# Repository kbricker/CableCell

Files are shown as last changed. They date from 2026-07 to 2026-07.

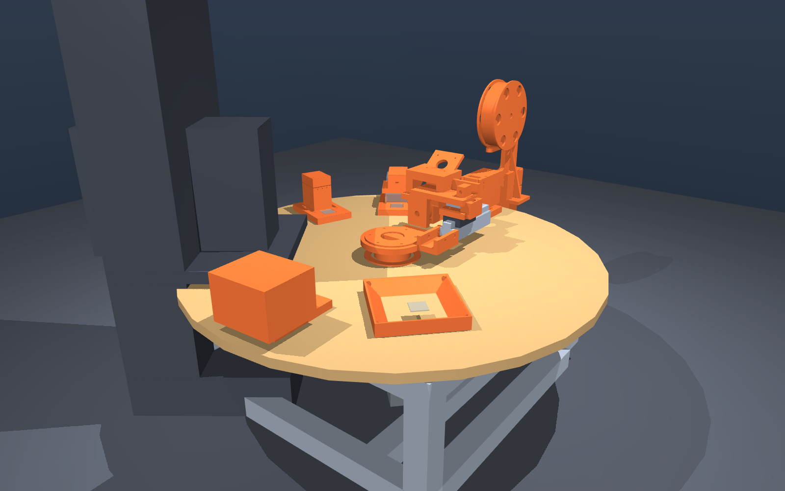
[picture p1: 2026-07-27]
sim/studies/renders/make_overview.png

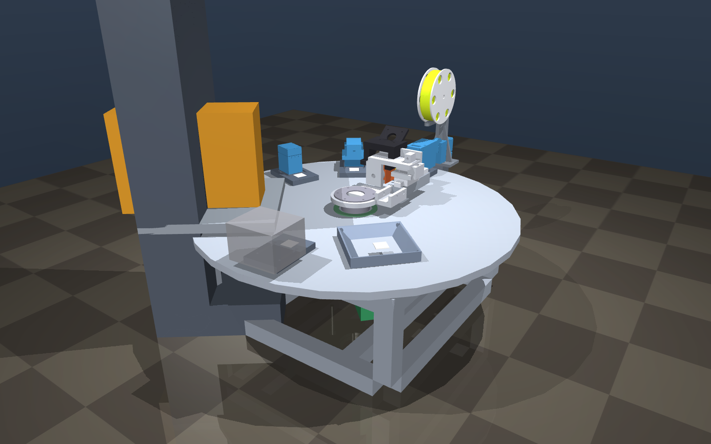
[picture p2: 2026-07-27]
sim/studies/renders/roughin_overview.png

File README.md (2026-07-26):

# CableCell

A benchtop robot cell that takes 22 AWG 3-conductor servo ribbon off a spool and
produces finished cables — split, strip, crimp Molex 5263 chain terminals, insert
into Mini-SPOX 5264 housings (50-37-5033, TRUE 2.50 mm pitch) on both ends, at a
commanded length.

> Load 20 housings into the cassette, a spool of ribbon, and a reel of pins.
> Tell the software: **3 cables, 5 inch total length.** It makes them and they
> drop into the collect bin as they complete.

**Architecture:** rotary indexing dial — six fixed stations on a bolt circle,
one arm carries the work to each. See `docs/cell-design.md`.

**First customer:** TendWright's STS3215 servo bus needs ~6–10 exact-length
joint-to-joint runs. That is a customer relationship, not ownership — CableCell
is its own project.

## Status

**Planning / design / simulation.** No code, no hardware, nothing ordered. The
sequence is deliberate: plan → research → design → simulate → source → build.
We do not buy until the sim says the layout closes.

## Layout

| Folder | Contents |
|---|---|
| `docs/` | Design of record, prior-art survey, decision log, sourcing index |
| `components/` | `registry.yaml` — the join between the BOM and the sim |
| `bom/` | Rendered buy lists with live vendor links |
| `cad/` | Vendor STEP files as downloaded, before conversion |
| `sim/` | MuJoCo rough-in: datums, scene assembly, reach/collision studies |
| `hardware/` | Printed and machined parts, once they exist |

## The component registry

`components/registry.yaml` is the single source of truth that both the BOM and
the simulation read. One entry per physical component: spec, vendor link, price,
sourcing status, and its model (CSG primitive parameters, or a mesh path once we
have a real one). Two lists that describe the same machine will drift; one list
that renders two views cannot.

## Modeling split

- **MuJoCo + CSG primitives** — layout and motion truth. Does the arm reach every
  station, does anything collide, does the cycle close. Precision does not live
  here; MuJoCo tessellates everything anyway.
- **FreeCAD (B-rep)** — manufacturing truth. Reads vendor STEP without fidelity
  loss, exports STL for the sim at a controlled deviation, and produces the
  dimensioned fabrication drawings via TechDraw.
- **Blender** — renders, visual mockups, quick blockouts.

## Hive

- **App:** CableCell (id 9) · modules Design / Applicator / Stations / Motion / Sourcing
- **Plan:** #657 — sourcing, de-risk bench, DIY ribbon-fed applicator

## License

This repository is dual-licensed, because it contains two different kinds of
work and a software license does not cleanly cover a CAD file.

| What | License | File |
|---|---|---|
| Software — `sim/`, scripts, anything executable | **MIT** | [`LICENSE`](LICENSE) |
| Documentation, CAD, hardware designs, BOMs — `docs/`, `cad/`, `hardware/`, `components/`, `bom/` | **CC BY 4.0** | [`LICENSE-CC-BY-4.0.txt`](LICENSE-CC-BY-4.0.txt) |

In plain terms: **take the code and do what you like as long as you keep the
copyright notice; take the designs and do what you like as long as you credit
me.** CC BY requires visible attribution in a way MIT does not — MIT only asks
that the license text travels with copies, which is notice preservation rather
than credit.

Neither license grants patent rights explicitly. That is deliberate.

Copyright (c) 2026 Kyle Bricker.

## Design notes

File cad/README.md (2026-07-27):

# cad/

Printed and machined parts as real CAD solids.

```
"%LOCALAPPDATA%/Programs/FreeCAD 1.1/bin/freecadcmd.exe" cad/build_parts.py
```

Regenerates everything in `parts/`. Each part exports three ways:

| Extension | For |
|---|---|
| `.FCStd` | open and edit in FreeCAD |
| `.step` | B-rep — other CAD, and TechDraw drawings |
| `.stl` | slicer, and mesh swap-in for the MuJoCo scene |

**Dimensions come from `sim/layout.py`**, the same single source the simulation
uses, so the printable parts and the sim cannot drift. Change a number there and
re-run both.

---

## Current parts

| Part | Size (mm) | Volume | What it is |
|---|---|---|---|
| `spool` | 110 × 110 × 31 | 116.6 cm³ | S1 ribbon spool. The wire ships as a loose roll, so this is ours to define |
| `spool_hanger` | 70 × 44 × 150 | 81.0 cm³ | Carries the spool axle, mounts to 3030 on 30 mm centres |
| `dancer_arm` | 82 × 12 × 20 | 6.2 cm³ | Passive tension; its flag is the spool-empty detect |
| `comb` | 26 × 32 × 12 | 9.3 cm³ | The gripper — a 3-channel **guide**, not a clamp |
| `guide_tube_mount` | 34 × 24 × 29 | 14.4 cm³ | Holds the PTFE tube that sets S1's presentation point |
| `measuring_wheel` | 31.8 × 31.8 × 9 | 5.3 cm³ | **Owns cable length accuracy.** 31.83 mm dia = 100.00 mm circumference |
| `spreader_plate` | 25 × 32 × 8 | 6.0 cm³ | S2's fan — diverging slots, 1.45 → 8 mm pitch over 25 mm |
| `z_platform` | 208 × 208 × 24 | 295.1 cm³ | Rides three posts, driven by one **off-axis** screw. Resolves the coaxial conflict |
| `radial_carriage` | 52 × 45 × 22 | 21.2 cm³ | MGN12 carriage + T8 nut. Takes the ~50 N pull-off thrust |
| `wrist_mount` | 50 × 32 × 26 | 12.0 cm³ | Carries the comb, flips 180° on mechanical hard stops |
| `camera_mount` | 60 × 48 × 34 | 29.5 cm³ | ELP board on the radial carriage — **not** the wrist, which flips |
| `drive_roller_block` | 56 × 30 × 46 | 67.0 cm³ | S1 feed nip. Drives and retracts; deliberately does **not** measure |
| `guillotine_holder` | 44 × 34 × 54 | 75.1 cm³ | S1 cut. Replaceable blade, close anvil clearance to shear not crush |
| `station_mount` | 76 × 60 × 40 | 46.6 cm³ | Generic station base with radial slots and an AprilTag ledge |

---

## Print notes

**Material.** *PETG where sustained load, creep or impact dominates; PLA+ where
dimensional accuracy or fine features dominate.* PLA creeps under constant
room-temperature stress in a way PETG does not, so anything permanently loaded is
PETG — `z_platform`, `station_mount`, `spindle_shaft`, `spool_hanger`,
`guillotine_holder`, `drive_roller_block`, `radial_carriage`, `wrist_mount`.

Everything else is PLA+, including — **revised** — the **comb**. An earlier note
here put the comb in PETG for toughness. That was the wrong call: its 1.8 mm
channels are the functional fit, sharper features beat toughness, and the load is
guide-only. Same reasoning puts `measuring_wheel` and `spreader_plate` in PLA+.

Per-part table and quantities in [`bom/bom-phase1.md`](../bom/bom-phase1.md) §7.
One 1 kg spool of each covers the build: ~720 g PETG, ~139 g PLA+.

**The comb is the part to be careful with.** Its channels are nominally
1.8 mm for a 1.4 mm conductor: only 0.2 mm clearance per side, and **FDM will
eat most of that.** Expect a 1.8 mm modelled slot to come out nearer 1.6 mm.
Print a short test coupon and check a conductor slides freely before committing
to a full comb — the channels must *guide*, never grip, or the whole
one-conductor-at-a-time premise fails.

**Orientation:**

| Part | Orientation | Why |
|---|---|---|
| `spool` | flange flat on the bed | Bore prints as a true vertical circle; no supports except the ribbon anchor slot |
| `spool_hanger` | on its back, upright flat on the bed | Axle bore axis vertical = round. Gussets and base need light support |
| `dancer_arm` | flat, as modelled | Trivial, no supports |
| `comb` | channels facing up | Channels are open-topped so they self-support; the lead-in funnels are the only overhang |
| `guide_tube_mount` | on its side, tube bore vertical | A horizontal 4 mm bore will sag; vertical prints round |
| `measuring_wheel` | flat, bore vertical | Rim concentricity is everything here — a wobbling wheel measures wrong |
| `spreader_plate` | flat, slots vertical through the plate | The lofted slots self-support; flared entries are the only overhang |
| `drive_roller_block` | on its back, motor face down | Keeps the ribbon slot and idler slot on the same layer plane, so the nip stays square |
| `guillotine_holder` | upright as modelled | **The 0.9 mm blade guideway is the critical feature** — print it vertical or it will not be straight |
| `station_mount` | flat, tag ledge up | Slots print clean; the ledge overhang is shallow enough to bridge |

**The measuring wheel has no rubber, deliberately.** A tyre or O-ring would grip
better but changes the effective circumference, and its compression varies with
preload — which is precisely the error the wheel exists to avoid. Grip comes from
a printed axial knurl plus light spring preload. Even so, treat 100.00 mm as
*nominal*: effective circumference depends on how far the ribbon compresses, so
it is a calibration constant measured at commissioning, not a number to trust.

**Tolerance reality.** Everything with a bore is modelled at nominal +0.15 mm
(the 8 mm axle bores are 8.3 mm) because printed holes come out undersize. The
comb channels are *not* similarly padded — they are a functional fit and want
measuring, not guessing.

---

## Two FreeCAD scripting traps, recorded so nobody re-finds them

1. **`Shape.translate()` mutates in place and returns `None`.** Chaining it —
   `face.extrude(v).translate(v2)` — silently yields `None`, and fusing that
   kills `freecadcmd` outright with no traceback. Build geometry at its final
   position instead, or use `translated()`.
2. **`freecadcmd` sets `__name__` to the module basename, not `"__main__"`.**
   A conventional `if __name__ == "__main__":` guard never fires, so the script
   imports cleanly and does absolutely nothing. `build_parts.py` accepts both.

Also worth knowing: routing an STL through a `Mesh::Feature` document object and
`Mesh.export()` crashes the process. Write the mesh directly —
`Mesh.Mesh(shape.tessellate(dev)).write(path)`.

`freecadcmd` swallows stdout and can die without a traceback, so
`build_parts.py` writes `cad/build.log` step by step. If a run produces nothing,
read that first.

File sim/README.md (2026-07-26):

# sim/

MuJoCo CSG rough-in. Answers **reach, collision and cycle-closure** — not
precision. MuJoCo tessellates everything; manufacturing truth lives in FreeCAD.

| File | What it does |
|---|---|
| `layout.py` | **The single source of every dimension.** Nothing else may hard-code one. Millimetres and degrees; each value carries a provenance status (COMMITTED / ESTIMATED / PLACEHOLDER) |
| `build_scene.py` | Generates `assets/cell.generated.xml` from `layout.py`; `--render` also writes PNG views |
| `run_cell.py` | Interactive viewer — regenerates the scene first, so edit-a-dimension-and-rerun is the whole loop |
| `studies/fit_check.py` | Arithmetic-only layout check: angular fit, Z budget, press reach |
| `studies/renders/` | Rendered views, committed so the layout can be reviewed without running anything |

## Run

```
uv sync
uv run python -m sim.layout                  # provenance: what is real, what is not
uv run python -m sim.studies.fit_check       # does the layout close?
uv run python -m sim.build_scene --render    # write MJCF + PNGs
uv run python -m sim.run_cell                # interactive viewer
```

## Frame convention

- world `z = 0` is the **bench top**
- world `x = y = 0` is the **pivot axis** (Datum B)
- the deck (Datum A) sits at `layout.DECK_ABOVE_BENCH`
- conversion mm → m happens once, in `build_scene.py`, never in `layout.py`

## Axes

Five joints model the arm: `Z` (assembly lift), `T` (theta, rotate), `R` (extend),
`S` (comb cross-slide), `W` (wrist flip). Ribbon feed (`F`) and nest index (`H`)
are station-local and not part of the arm kinematics.

`assets/cell.generated.xml` is generated — do not edit it. Change `layout.py`.

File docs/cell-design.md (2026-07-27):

# CableCell v1 — Full Design Document

**Date:** 2026-07-24 · **Hive:** app 9 (CableCell), plan #657
**Supersedes:** the layout sketches in `exploration-and-thumbnail.md` (that doc remains the prior-art survey and decision log).
**Architecture:** rotary dial (Kyle 2026-07-24) — fixed stations on a bolt circle, one arm carries the work to them.

---

## 1. The job this machine exists to do

> Load 20 housings into the cassette, a spool of ribbon, and a reel of pins. Tell the software: **3 cables, 5 inch total length.** It makes them and they drop into the collect bin as they complete.

That is the acceptance test, stated as a spec:

| | |
|---|---|
| **Input consumables** | 20× Molex 50-37-5033 housings (cassette) · 1 spool 22 AWG 3-conductor servo ribbon · 1 reel Molex 0008701039 terminal chain |
| **Job command** | `qty=3, length=127.0 mm (5.00"), recipe=SPOX-3P` |
| **Output** | 3 finished cables, connector on both ends, in the collect bin |
| **Consumed** | 6 housings, 18 terminals, ~420 mm of ribbon (3 × 127 mm + kerf/lead-in) |
| **Untouched** | 14 housings still in the cassette |
| **Unattended** | Yes — operator loads, presses Run, walks away |

**Length definition (matters, gets calibrated):** *total length* = tip of connector A to tip of connector B. The machine works internally in **ribbon length** and applies a per-recipe constant (`connector_offset`) for the amount of wire consumed inside each housing. Calibrate once by measuring a produced cable; store in the recipe.

**Length envelope:** minimum ~90 mm (set by 2 × split length + handling clearance), maximum ~1000 mm (set by the payout trough). 127 mm sits comfortably in range.

**Capacity per load:** 20 housings = 10 cables. A 15 m ribbon spool at 127 mm = ~110 cables. A 5000-terminal reel = ~830 cables. **Housings are the binding constraint** — by design, since they're the one thing a human loads by hand.

---

## 2. Machine overview

A rotary indexing cell. Six stations sit on a bolt circle. One **arm** pivots between them and extends radially into whichever station it faces. Nothing else moves the workpiece.

```
                       ┌──────── S2 SLIT + FAN ────────┐
                       │                                │
        S1 FEED / CUT ─┤          ●  pivot              ├─ S3 STRIP
        (spool, rollers│         ╱                      │
         guillotine)   │        ╱  arm  ──► extends     │
                       │       ╱   radially into        │
        S6 DROP ───────┤          whichever station     ├─ S4 CRIMP
        (collect bin + │          it is facing          │   (press +
         reject bin)   │                                │    applicator)
                       └──────── S5 INSERT ─────────────┘
                                 (housing cassette,
                                  nest, pusher)
```

**Why rotary:** repeatability comes from mechanical detents at each sector rather than a long rail staying square; each station is a bolt-on module in its own sector (which is precisely how "other connectors later" arrives — a new insert sector plus a new cassette); and the circle fits the working stations in less bench space than a 900 mm rail. The reject bin costs nothing — it is simply another angular position.

> **Bolt circle corrected 2026-07-26.** This section previously claimed a ~300 mm circle. It does not close: seven stops (six stations plus reject) with a 210 mm-wide press need **274.4° of a 270° arc** at R₀ = 150 mm. The working value is **R₀ = 200 mm** — a 400 mm circle — which needs 201.8° and leaves 68° spare. Minimum viable is ~175 mm. Computed by `sim/studies/fit_check.py`; table in `docs/datums.md`. The original figure was written for *five* stations, before the press was understood as a standalone machine.

**Working arc, not a full turn.** The arm sweeps ~270° and returns. The trailing ribbon sweeps with it but never wraps the pivot, so no slip ring and no rotary air union are needed — a service loop and drag chain carry power and air to the arm.

### 2.1 The arm (the only thing that moves the work)

Three things ride on the arm:

- **Comb** — the gripper. Not a plain clamp: a **3-channel guide** that keeps each conductor individually addressable. The channels *guide*; they do not clamp. The **ribbon body is clamped** behind the split, so each conductor can slide freely in its own channel — which is what lets a pusher advance one conductor at a time at the insert station.
- **Cross-slide** — a short lateral axis (~20 mm) that indexes which conductor sits on the station work line. One conductor at a time to the crimp anvil; one conductor at a time to the insertion axis. Comb channel pitch is **8 mm**, deliberately *not* the 2.5 mm connector pitch — see §5.4.
- **Wrist** — a 180° flip. Needed because the two ends of a cable are born pointing in opposite directions (§3, step 7). It only ever needs two positions, so it is a **pneumatic rotary actuator with adjustable hard stops**, not a servo.

---

## 3. Full cycle — one cable, step by step

Running the 3 × 127 mm job. Steps 1–13 repeat three times.

**End A (still attached to the spool — the spool is the anchor)**

1. **Present.** Feed rollers advance ribbon until ~30 mm protrudes past the guillotine at S1.
2. **Grip.** Arm at S1, comb closes on the ribbon body; ~28 mm of tail projects radially outward.
3. **Slit + fan (S2).** A two-blade die notches both webs back 25 mm from the tip. A spreader plate then splays the three tails into the comb's 8 mm channels. Ribbon body stays clamped throughout.
4. **Strip (S3).** A 3-position V-blade die closes on all three conductors at comb pitch; the arm retracts ~4 mm to slip the slugs. Strip length 2.5–3 mm. Three slugs drop to the waste chute.
5. **Crimp ×3 (S4).** For each conductor *i*: cross-slide indexes conductor *i* onto the anvil line → station wire-clamp holds it → press fires one stroke → applicator crimps the terminal and severs it from the carrier → load cell records the force curve → cross-slide advances 8 mm. Carrier scrap exits to its own bin. Three pins now stand on the fanned tails at 8 mm spacing.
6. **Insert ×3 (S5).** Escapement drops one housing from the cassette into the nest; nest clamp closes. Then for each conductor *i*: cross-slide brings conductor *i* onto the **fixed insertion axis** → pusher finger closes on the wire ~5 mm behind the pin → drives forward until the housing lance clicks → pulls back 1.5 mm against a stop (retention test, load cell) → releases → **nest indexes one 2.5 mm pitch** so the next cavity arrives on the same fixed axis. Already-inserted conductors travel *with the housing*, so nothing is strained and the tooling only ever works at one spot. Camera checks black/red/white land in cavities 1/2/3. Nest clamp opens; end A is complete.

**Payout and cut**

7. **Pay out.** Arm returns to a defined **payout reference position** holding the finished end A, so the tube-to-comb distance is a known constant. Feed rollers pay out ribbon until `ribbon_length = 127 mm − connector_offset`, measured by the independent encoder wheel (not by counting steps — ribbon slips). Slack sags into the payout trough.
8. **Hand off.** Arm releases end A into the trough and returns to S1, gripping the ribbon on the *piece* side of the guillotine.
9. **Cut.** Guillotine severs. The arm now holds the cable by end B; the finished connector A dangles in the trough. The spool's new leading end waits at the tube for the next cable.
10. **Flip.** Wrist rotates 180°, so end B's tail now projects radially outward exactly as end A's did in step 2. **Every station sees identical geometry for both ends** — this is what the wrist buys, and why it isn't optional.

**End B**

11. **Repeat 3–6** on end B. Same stations, same tooling, same motions, second housing.
12. **Drop.** Arm indexes to S6 over the collect bin, comb and body clamp open, finished cable falls. On any fault flag (crimp force out of band, retention fail, camera mismatch) the arm drops at the **reject** angle instead and logs why.
13. **Next.** Feed rollers advance the spool's new leading end past the guillotine. Go to step 2.

**Job end:** after cable 3, the machine parks, reports `3/3 complete, 0 rejects, 6 housings used, 14 remaining`, and idles.

---

## 4. Cycle time

| Phase | Ops | Est. |
|---|---|---|
| Grip + slit + fan + strip | 4 moves, 3 strokes | ~12 s |
| Crimp ×3 | 3 index + 3 strokes | ~15 s |
| Insert ×3 | 3 index + 3 push/verify + 3 nest index | ~20 s |
| **Per end** | | **~47 s** |
| Payout, handoff, cut, flip | | ~15 s |
| **Per cable** (2 ends + payout) | | **~110 s** |
| **3 × 127 mm job** | | **~5.5 min** |

Commercial machines do this in 7–9 s per cable. We are ~15× slower and roughly 40× cheaper — the right trade for batches of ten.

---

## 5. Mechanical parts — what each one is for

### 5.1 Frame and rotary axis

| Part | Function |
|---|---|
| Aluminum extrusion frame (3030) + 10 mm tooling-plate deck | Rigid datum (Datum A). Every station bolts to the deck on the same bolt circle, so station geometry is set by hole position, not by shimming. |
| **Z stage** — commodity ballscrew linear module (SFU1605 + dual rails + NEMA 17/23) | **Carries the entire rotating assembly.** Lets each station have its own engagement height instead of forcing all seven to one shimmed plane, and provides vertical clearance for rotation. Stack is base → Z → rotary → arm. Stiffness-critical: it sits at the bottom of a long lever, so its compliance shows up magnified at the comb. Prefer the shortest travel that works. See `datums.md`. |
| **Main bearing** — large-bore thin-section or tapered roller, ~80–100 mm | Carries the arm. Must take the *radial extension load* and the reaction from insertion pushes without deflecting more than ~0.05 mm at the comb. |
| Arm rotary drive — NEMA 17 + 5:1 belt reduction, or NEMA 23 direct | Indexes between sectors. Reduction buys resolution and holding torque against station reaction forces. |
| **Detent/index plate** — hardened bushing + spring-loaded or pneumatic plunger per sector | Repeatability. The stepper gets *near* the sector; the detent puts it *exactly* there. This is why rotary beats linear on precision-per-dollar. |
| Drag chain / service loop | Carries the arm's air lines (comb clamp, wrist), stepper cable, and sensor wiring across a ±135° sweep **plus the Z stroke**. No slip ring needed. |

### 5.2 The arm assembly

| Part | Function |
|---|---|
| Radial slide — MGN12 rail + carriage, belt or leadscrew, NEMA 17 | The shared "extend into the station" motion. Every station uses it; this is the big saving of the rotary layout. |
| **Comb** — machined or printed 3-channel guide, hardened channel inserts | Keeps each conductor individually addressable and at a known pitch. Channels guide only. Swappable per connector recipe. |
| **Body clamp** — pneumatic cylinder + serrated pad | Clamps the *unsplit ribbon* behind the comb. This is the actual grip; it takes all handling load, so conductors stay free to slide. |
| Cross-slide — MGN9 + 20 mm leadscrew, NEMA 17 | Indexes conductor *i* onto the work line at crimp and insert. |
| **Wrist** — pneumatic 180° rotary actuator with adjustable stops | Flips end B into end A's orientation. Two positions only, so no servo. |

### 5.3 S1 — Feed / measure / cut

| Part | Function |
|---|---|
| Spool holder + spring dancer arm | Passive payoff at constant light tension; dancer flag doubles as spool-empty detect. |
| Drive rollers (knurled steel + polyurethane idler, spring preload) NEMA 17 | Pays ribbon out and pulls it back. |
| **Measuring wheel + rotary encoder** (independent of the drive) | Owns cable length accuracy. Never trust drive-roller steps — ribbon slips. Closed loop on this encoder. |
| PTFE-lined guide tube | Delivers the ribbon to a repeatable presentation point regardless of spool behaviour. |
| **Guillotine** — hardened blade + anvil, pneumatic | Square full-width cut. Blade geometry must not crush the ribbon end (a crushed end won't enter the comb channels). |
| Payout trough | Receives slack and the dangling finished end A during payout. Keeps a 1 m cable out of the mechanism. |

### 5.4 S2 — Slit + fan

| Part | Function |
|---|---|
| **Two-blade slitting die**, depth-adjustable to 0.05 mm, pneumatic | Notches both webs simultaneously to the recipe's split length (25 mm). Depth control is the whole game — too shallow and it won't zip, too deep and it nicks copper. |
| Spreader plate — diverging slots, pneumatic | Splays the three split tails from the ribbon's **1.40 mm** pitch out to comb pitch (8 mm) and captures them in the comb channels. **7.5° splay** — gentle enough to take no set in the insulation. |
| Backing anvil | Supports the ribbon so the blades cut rather than push. |

**Ribbon pitch is 1.40 mm, not 2.5 mm** (vendor spec 2026-07-27; the 2.5 mm was the connector cavity pitch borrowed by mistake). And the ribbon is **designed to separate by hand**, which may reduce this station to a printed splitting wedge — see `docs/stations.md` §2.

**Why 8 mm and not 2.5 mm:** the fan pitch is a free parameter, and widening it is what removes the pin-to-pin collision risk at the crimp anvil. Convergence back to the connector's 2.5 mm never happens mechanically — pins are inserted one at a time, so the cross-slide handles it in software.

### 5.5 S3 — Strip

| Part | Function |
|---|---|
| 3-position V-blade die at comb pitch, pneumatic | Scores all three conductors in one stroke — equal strip length by construction. |
| Depth stop, per-recipe shim | Sets score depth for 22 AWG. Wrong depth = nicked strands = the crimp fails a pull test later. |
| Slug waste chute | The three insulation slugs drop away rather than into the mechanism. |

(The *pull-off* is done by the arm retracting 4 mm — no dedicated actuator.)

### 5.6 S4 — Crimp

| Part | Function |
|---|---|
| **Bench press, 1.5–2 T, 30–40 mm stroke** (electric motor-and-cam) | The force. Dumb by design; all per-terminal intelligence lives in the applicator. Pneumatic route dropped 2026-07-25. **Bought, never built** (Kyle 2026-07-26) — and placed *first*, as the layout datum: its anvil fixes θ₄ and one bolt-circle point, its crimp height fixes Z₄. |
| **Mini-applicator** for Molex 5263 chain — donor XH2.5 clone, custom-tooled unit, or our own build | Indexes one terminal per stroke off the bandolier, forms wire + insulation crimps, severs the carrier. **The one part we do not improvise** (see the applicator subproject, §9). |
| Terminal reel arm + drag brake (spring steel strip) | Constant back-tension on the chain. Loose chain = mis-feed = the single most common failure mode on real machines. |
| Chain guide + terminal-present optical sensor | Detects mis-feed *before* a stroke fires on an empty anvil. |
| Station wire clamp, pneumatic | Holds the conductor axially during the crimp stroke. |
| **Load cell + amplifier on the press ram** | Crimp-force curve per stroke — the standard in-line QA signal. Out-of-band → flag the cable for the reject bin. |
| Carrier scrap chute + bin | Severed carrier strip has to go somewhere. |

### 5.7 S5 — Insert

| Part | Function |
|---|---|
| **Housing cassette** — printed stick magazine, keyed cross-section, spring follower | Holds ~25 housings in one orientation. The friction-lock ramp keys them so they physically cannot load backwards. **Swappable per connector family** — this is the roadmap seam. |
| Escapement — sliding shutter, pneumatic | Releases exactly one housing per cycle. |
| Nest — pocket matching the housing profile + pneumatic clamp | Holds the housing rigidly and backs it up against insertion force. |
| **Nest index slide** — NEMA 17 + leadscrew, 2.5 mm steps | Brings cavity *i* to the fixed insertion axis. *The housing moves, not the wires* — this is the design's key move. |
| Funnel guide — tapered entry, ±0.3 mm capture | Forgives pin position error at the cavity mouth. |
| **Pusher** — finger/collet on a short pneumatic stroke + load cell | Closes on the **wire ~5 mm behind the pin** (never on the pin — a pin must not be loaded through its crimp), drives until the lance clicks, then pulls back 1.5 mm against a stop for the **retention test**. |
| Housing-present + low-stack optical sensors | Don't fire into an empty nest; warn before the cassette runs out. |
| Camera (USB) + LED ring | Verifies black/red/white in cavities 1/2/3 before the housing leaves the nest. USB rather than CSI since the supervisor is a NUC. |

### 5.8 S6 — Output

| Part | Function |
|---|---|
| Collect bin + chute | Finished cables drop here as they complete. |
| Reject bin | A separate angular position — costs one bracket. A machine without a reject path silently ships bad parts. |

### 5.9 Guarding

| Part | Function |
|---|---|
| Polycarbonate guard around the press + arm sweep, interlock switch | The press is 1.5 T. Guarding is not optional. |
| E-stop, hard-wired | Cuts 24 V motor and valve power directly — not via software. |

---

## 6. Electrical / electronic parts — what each one is for

### 6.1 Compute

| Part | Function |
|---|---|
| **Spare NUC on Ubuntu** (8 GB, SSD) | Supervisor. Job queue, cable state machine, recipes, calibration constants, web HMI, camera inspection, logging, and the agent that reports cell status into Hive. Pi 5 cut 2026-07-24: the split-brain design already makes the supervisor architecture-independent, Kyle has a stack of NUCs, and x86 + a real SSD beats ARM + SD card for a machine running unattended jobs. $0. |
| **Motion controller** — BTT Octopus (8 driver slots) or Duet 3 Mini, running Klipper or grblHAL | Real-time step generation and endstop handling. The supervisor cannot hold microsecond step timing while serving a UI; this split is standard practice. 8 slots leaves headroom for the 6 axes. |
| 24 V / 350 W PSU | Steppers, valves, sensors. |

### 6.2 Motion — 6 stepper axes

| Axis | Motor | Purpose |
|---|---|---|
| θ — arm rotate | NEMA 17 + 5:1 reduction | Index between station sectors |
| **Z — assembly lift** | **NEMA 17/23 + SFU1605 ballscrew** | **Per-station engagement height; lift to clear tooling before rotating** |
| R — arm extend | NEMA 17 + leadscrew/belt | Radial move into every station |
| S — comb cross-slide | NEMA 17 + 20 mm leadscrew | Select conductor 1/2/3 |
| F — ribbon feed | NEMA 17 + rollers | Payout and retract; length |
| H — housing nest index | NEMA 17 + leadscrew, 2.5 mm steps | Bring cavity *i* to the insertion axis |

Drivers: 6× TMC2209 (quiet, and sensorless homing removes switches if it proves reliable).

**Z holding is a safety item, not a performance one.** A ballscrew is efficient
enough to back-drive under load, so on a vertical axis carrying the whole
rotating assembly an E-stop could drop the arm. Resolve deliberately: self-locking
trapezoidal leadscrew, or ballscrew plus motor brake, or ballscrew plus
counterbalance. **Open.**

**Homing order:** Z homes to its up position before θ is permitted to rotate, or
the arm can sweep into station tooling on power-up.

### 6.3 Pneumatics — ~10 actuators

Compressor (1–2 gal quiet, ~$150) · **filter + regulator** — deliberately *not* a full FRL, since a lubricator injects oil into the air and that is the last thing we want near crimp tooling · 10-station manifold · 24 V solenoid valves (5/2 double-acting, 3/2 single-acting) · MOSFET outputs from the motion board or a driver breakout.

**Air is deferred to cell build.** With the press electric rather than pneumatic, nothing in the de-risk phase needs compressed air — $165 out of the near-term bucket (2026-07-25).

1. Body clamp · 2. Wrist 180° rotary · 3. Slit blades · 4. Spreader · 5. Strip blades · 6. Guillotine · 7. Press ram · 8. Insert pusher · 9. Housing escapement · 10. Nest clamp

Plus the sector detent plunger if it is pneumatic rather than sprung.

### 6.4 Sensors

| Sensor | Purpose |
|---|---|
| 5× home/endstop switches (θ, Z, R, S, H) | Datum on power-up. Z homes up first — see §6.2. |
| **Ribbon measuring encoder** | Closed-loop cable length — the accuracy-critical sensor |
| **Load cell + HX711/ADS1232 on press ram** | Crimp force curve → crimp QA |
| **Load cell on insert pusher** | Insertion click + pull-back retention test |
| Terminal-present optical (applicator) | Catch chain mis-feed before a wasted stroke |
| Housing-present (nest) + low-stack (cassette) | Don't insert into nothing; warn before running dry |
| Ribbon-out / dancer flag | Spool empty |
| Air pressure switch | Refuse to run on low air — a half-stroke crimp is worse than no crimp |
| USB camera + LED ring | Wire color/position verification |
| Guard interlock + E-stop | Safety |

---

## 7. Control software

**Layers.** Klipper/grblHAL on the MCU (motion primitives) ← Python supervisor on the NUC (state machine, recipes, QA) ← web HMI (job entry, status) + Hive agent (fleet reporting).

**Recipe** (per connector family — the "other connectors later" seam, in data rather than code):
```
SPOX-3P: conductors=3, cavity_pitch=2.5, comb_pitch=8.0,
         split=25.0, strip=2.75, insert_depth=6.0, pullback=1.5,
         crimp_force_band=[x,y], connector_offset=<calibrated>,
         cassette=SPOX-3P-v1, applicator=MOLEX-5263
```

**Job:** `{qty, length_mm, recipe}` → a queue of cable state machines, each running the §3 sequence.

**Every station reports pass/fail.** A cable that fails crimp force, retention, or camera check is flagged, completes its cycle, and drops in the reject bin with a logged reason. Nothing silently ships.

**Faults that stop the run:** no air, terminal mis-feed, cassette empty, spool empty, guard open, any axis losing home.

**Calibration constants** (stored, re-measurable): `connector_offset`, feed reference offset, per-sector angular positions, **per-station engagement heights Z₁…Z₇**, `Z_clear`, **payout reference Z**, strip depth shim, insertion depth, crimp force band.

The per-station Z table is what the base-mounted Z axis buys: station heights
become seven numbers touched off at commissioning rather than a single plane every
station must be mechanically shimmed to. `payout_z` matters because changing Z
changes the ribbon's free length between S1's guide tube and the comb — payout is
length-critical, so it only ever happens at one height.

**HMI:** enter qty + length + recipe, press Run, watch progress. Machine reports `n/N complete, r rejects, h housings remaining`.

---

## 8. What still needs proving before fabrication

Ranked. Items 1–2 are the printed-mockup work already in plan #657.

1. **Crimp quality with a real applicator** (de-risk A). Everything downstream assumes a good pin.
2. **Insertion + pull-back repeatability** (de-risk B), including the funnel's real capture window — which sets how good the arm's positioning must be.
3. **Slit depth window** on the actual ribbon — the difference between "zips cleanly" and "nicked strand."
4. ~~**Fan geometry**~~ — **PARTIALLY ANSWERED 2026-07-26.** The splay half is settled: from the ribbon's real ~1.45 mm pitch out to 8 mm comb pitch over a 25 mm split, each outer conductor moves 3.275 mm laterally — **7.5°**. Gentle enough that the insulation takes no set and the breakout will not look mangled. The applicator-throat clearance half stays open until the donor applicator is measured. See `docs/stations.md` §2.
5. **Arm stiffness under insertion load** — total compliance from Z carriage → rotary bearing → arm → radial slide → comb, versus the funnel's capture window. The Z stage sits at the bottom of a long lever, so its angular deflection is magnified at the comb; it is now the first term in this budget, not an afterthought.
6. **Slack behaviour during payout** — does the trough actually control a 127 mm cable's dangling end, and a 1 m one?
7. **Z travel envelope** — what max(Zᵢ) − min(Zᵢ) actually turns out to be once the press crimp height and station tooling heights are known. Drives stage cost and stiffness; wants the smallest defensible number.

---

## 9. Relationship to the applicator subproject

§5.6 lists the applicator as bought. Kyle's decision is to **build a ribbon-fed applicator** for the 5263 chain as a parallel subproject (its own module, `CableCell/Applicator`). The interface contract keeps the two tracks independent: **standard mini-applicator envelope and shank, side feed, same shut height.** Whatever we build drops into the same press and the same S4 bracket as the purchased donor — so the cell can be finished and producing cables on bought tooling while the applicator build proceeds on its own timeline, and swapping it in later is a bolt change.

---

## 10. Cost roll-up

| Bucket | Est. |
|---|---|
| Consumables (housings, terminals, ribbon) | ~$100 |
| Press + applicator + metrology | ~$560–800 |
| Compressor + filter/regulator + valves + manifold + cylinders | ~$400 |
| Compute (NUC $0, motion board, PSU, wiring) | ~$250 |
| Motion (6 steppers, drivers, rails, bearing, belts) | ~$400 |
| **Z stage** (ballscrew module + brake or leadscrew) | **~$100–250** |
| Frame, deck, printed stations, blades, dies | ~$350 |
| Sensors (encoder, 2 load cells, optical, camera) | ~$150 |
| **Total** | **~$2,300–2,700** |

Against ~$15–60k for the commercial equivalent — and it makes exactly the cable we need, in batches of ten, from a cassette a human can load in under a minute.

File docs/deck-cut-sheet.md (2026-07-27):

# Deck cut sheet

*Generated by `sim/studies/deck_cut_sheet.py` — do not edit by hand. Re-run it if R₀ or the station layout changes.*

```
CableCell deck - cut sheet
==============================================================

Material: 1/2" plywood or MDF (12 mm nominal). Void-free ply if you
have it - the station bolts land near the top face.

feature                                   inches           mm
--------------------------------------------------------------
Outside diameter                        22-1/16"     560.0 mm
Thickness                                   1/2"      12.0 mm
Centre clearance hole                         7"     177.8 mm
Station bolt circle diameter             15-3/4"     400.0 mm
Mounts above bench top                    6-7/8"     174.0 mm

STATION POSITIONS - 7 stops on the bolt circle
Angles from S1, positive counter-clockwise viewed from above.

stop              angle     chord from S1
--------------------------------------------------------------
s1 feed            0.0 deg             0"
s2 slit           63.8 deg        8-5/16"
s3 strip         127.6 deg        14-1/8"
s6 drop          198.8 deg       15-9/16"

Chord = straight-line distance from the S1 hole across the face.
Easier to lay out with a tape than to protract an angle.

PER-STATION HOLES - 4 per stop
  Rectangle 1-1/8" radial x 1-9/16" tangential
  (28 x 40 mm), centred on the bolt circle at each angle.
  Drill 1/4" (6.5 mm) clearance for M5 hardware.
  The printed station mounts are slotted radially, so a little
  drift is absorbed at assembly.

S6 DROP HOLE - NOT on the bolt circle
  At the S6 drop angle (198.8 deg).
  A reject chute is DEFERRED - if it comes back it is a second
  slot of the same size at its own angle.
  Slot 2-3/4" radial x 2-1/2" tangential (69 x 64 mm),
  running from 4-13/16" to 7-9/16" from centre (123 to 192 mm).
  This stop gets NO station mount - the mount would roof over
  the hole. The printed collar bolts around each slot instead.
  Inboard edge is set by the Z platform's CORNERS passing
  underneath at 117 mm - the platform is square,
  so its corners reach further than its edges.

PRESS SCALLOP - NOT CUT YET
  The press is stashed for the prototype. Leave the rim whole.
  When it comes back it wants a scallop cut IN FROM THE RIM at
  its stop angle, oversize and fitted to the real machine - the
  ram-axis depth is still unmeasured. Cutting it now would be
  removing wood to fit a number nobody has.

TOLERANCE
  Bolt-circle diameter within +/- 1/16" is fine. The station mounts are
  slotted, and every station's height is calibrated in software at
  commissioning - the wood is not holding the precision.
```

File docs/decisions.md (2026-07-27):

# Decision log

Running log of decisions that shape the machine. Newest last. Every entry names
who decided and when, so a stale doc can always be traced back to the call that
made it stale.

---

**2026-07-24 — CableCell is its own project.** Kyle: "building this cable making
cell is a new project." Registered as Hive app 9. TendWright is CableCell's first
*customer*, not its owner.

**2026-07-24 — Rotary dial architecture.** Six fixed stations on a bolt circle,
one arm carries the work. Chosen over a linear rail: mechanical detents beat a
long rail staying square, each station is a bolt-on sector module (which is how
"other connectors later" arrives), and a ~300 mm circle fits five working
stations in less bench space than a 900 mm rail.

**2026-07-24 — Housing feed is a hand-loaded printed stick cartridge.** Swappable
per connector family. This is the roadmap seam for other connectors.

**2026-07-24 — Build the ribbon-fed applicator, don't buy it.** No off-the-shelf
clone applicator exists for 5264/SPOX. Donor is an XH2.5 OTP clone bought as a
chassis and mechanism reference. Punch/anvil route order: transplant → buy
inserts → machine. Sedeke custom-tooling quote is the parallel path.

**2026-07-24 — Supervisor is a spare NUC on Ubuntu; Pi 5 cut.** The split-brain
design already puts all real-time work on a dedicated motion MCU, so the
supervisor is architecture-independent. Kyle has a stack of NUCs. Cost
$100–140 → $0. Knock-on: USB camera instead of Pi Camera 3 on CSI.

**2026-07-25 — Pneumatic press route dropped.** Kyle: "the pneumatic I found — if
it's not what we need, skip it." The press will be a conventional electric
applicator press. Knock-on: de-risk A needs no compressed air, so the compressor
and filter/regulator defer to cell build — $165 out of the buy-now bucket, and
air leaves the critical path entirely.

**2026-07-25 — Terminal packaging resolved.** Molex 0008701039 ships only as Cut
Tape (min 100) or Tape & Reel (min 12,000). No loose-piece exists, so every form
is carrier-strip and applicator-feedable. This was the risk that could have
killed the applicator subproject.

**2026-07-25 — The BOM markdown is the sourcing deliverable, not an Amazon List.**
The Amazon List UI is slow, flaky and token-expensive. Search there; record here.

**2026-07-26 — CableCell gets its own repo** at `C:\Projects\CableCell`,
following the TendWright pattern. Design docs move out of
`overwatch/reports/cable-robot-cell/`. No git remote configured yet — public vs.
private undecided.

**2026-07-26 — Modeling split: MuJoCo for layout truth, FreeCAD for manufacturing
truth.** Blender is a mesh modeler with no constraints and no true circles; CAD
is B-rep and tolerance appears only at tessellation, which we control. MuJoCo
tessellates everything anyway, so precision never lived in the sim. FreeCAD
chosen over Onshape Free (all free-tier documents are public) and Fusion Personal
(license churn): it reads STEP natively, exports STL at controlled deviation,
produces dimensioned drawings via TechDraw, and is scriptable in Python. FreeCAD
1.0 fixed the topological naming problem that made it unusable historically.
Blender retained for renders, mockups and blockouts.

**2026-07-26 — Two shut-height standards found; applicator leads, press follows.**
135.78 mm (Molex/TE/Mecal) vs 119.7 mm (Chinese OTP clone) — a 16 mm mismatch
that makes the two incompatible. Adds a fifth question to the line 10 seller
message, and makes the applicator purchase the gate on the press purchase. See
`datums.md`.

**2026-07-26 — FreeCAD approved and installed** (1.1.2, winget). Tool install
only; nothing enters `pyproject.toml`.

**2026-07-26 — The press is the layout datum, not the dial.** Kyle. Place the
press first; its anvil fixes θ₄ and one bolt-circle point, its crimp height fixes
Z₄. The pivot then goes at R₀ from there and the other six stops follow. A
30–50 kg machine with a fixed vertical ram does not get to be a bolt-on sector
module.

**2026-07-26 — Do not attempt to reproduce the press.** Kyle: preliminary
research indicates the crimp station is not easy to reproduce with our own
system. Buy it. Revisit building one as a possible side project *later*, once we
have a unit in hand to analyse. Note this is narrower than the applicator
subproject, which remains a build.

**2026-07-26 — Base-mounted Z axis added.** Kyle: "the main arm that rotates can
also have a vertical span... a base with a vertical movement extension setup,
with the rotator anchored on the top of that." Stack is base → Z stage → rotary →
arm, so Z carries the whole rotating assembly. Commodity ballscrew linear stage
class (SFU1605 + dual rails + NEMA 17/23, $62–200).

Consequences:
- **Work-line Z is no longer a single datum.** It becomes a per-station table
  Z₁…Z₇ in config, calibrated at commissioning. This removes the dependency chain
  that previously blocked the entire layout on the applicator's wire height.
- **Rotation clearance becomes vertical** (lift, rotate, descend) instead of
  radial, decoupling station tooling design from the arm's sweep path.
- Axis count 5 → 6 steppers (θ, Z, R, S, F, H). BTT Octopus has 8 slots — no
  re-sizing.
- New risks: Z-carriage compliance at the bottom of a long lever adds to the comb
  deflection budget; ballscrews back-drive, so an E-stop could drop the arm
  unless braked or a self-locking leadscrew is used; Z changes the ribbon's free
  length, so the payout reference position must include a Z.
- Homing gains an ordering rule: Z homes up before θ may rotate.

**2026-07-26 — Repo is public, dual-licensed MIT + CC BY 4.0.** MIT covers
software; CC BY 4.0 covers docs, CAD, hardware designs and BOMs. Reason for the
split: MIT is a software license and maps badly onto a STEP file or a design doc.
Reason for CC BY specifically: it requires *visible attribution*, which is what
Kyle meant by "free to use with a citation" — MIT only requires notice
preservation, which is weaker and does not oblige anyone to credit him anywhere a
human will see.

Apache-2.0 was considered and **rejected**. It was raised for its explicit patent
grant, but that grant runs *from* the author *to* users — as sole author, Kyle
would be granting away rights to any patent he later holds on the applicator
mechanism. For a solo inventor with a plausible novel mechanism, no explicit grant
preserves more optionality. Neither MIT nor CC BY grants patent rights, and that is
deliberate.

**2026-07-26 — The Z stage cannot be a single coaxial ballscrew module.** Found by
the MuJoCo rough-in: a rotary axis cannot pass through the middle of a linear
rail, and the pivot needs the space the rail wants. Options are (a) cantilever the
rotor off one module's carriage, (b) a Z platform on 3–4 guide posts with one
off-axis ballscrew, (c) move Z onto the arm. Also found: the press body passes
through the deck disc (130→340 mm radius against a 280 mm deck) — fix by
scalloping the tooling plate where the press lands.

**2026-07-26 — The deflection budget is about variance, not strength.** Kyle:
these cables are small and light, worst case 3–4 ft, nowhere near a pound. Correct
and decisive — a 1.2 m length of the ribbon is ~15–20 g against a ~2 kg rotating
assembly, so payload is ~1% of moving mass and irrelevant to any load
calculation.

The real budget is *arriving inside the insertion funnel's capture window*
(pencilled ±0.3 mm, ≈1.5 mrad across the whole stack at 200 mm reach). That makes
it a precision problem, and precision cares about **variance**: with a constant
~20 g payload, a cantilever's sag is *repeatable*, and repeatable sag folds into
the station Z table as calibration rather than error. What defeats a cantilever is
backlash, stick-slip and thermal drift, not droop.

**Consequence: the Z architecture decision is deferred and explicitly gated on
measuring the funnel capture window in de-risk B (657.3).** Option (a) is now the
likely answer. Measuring it costs $20 of PLA; insuring against it costs $150 of
ballscrew. This promotes 657.3 from "an experiment" to a prerequisite for a design
decision.

**2026-07-26 — Cable length envelope confirmed at ~1000 mm.** Kyle: "3.3 ft is
perfectly fine for now, way larger than any early prototype I have planned." The
figure in `cell-design.md` stands; the payout trough is sized to it.

**2026-07-27 — One engagement plane, derived from the tallest part. Z stroke
halves.** Kyle, asked whether to derive `STATION_Z` per stop: *"yes on the
station z question, we want to make the travel needed as minimal as possible."*

Those two things pull against each other, and the resolution is the interesting
part. Deriving a height *per station* from that station's tallest part gives
every stop a different height — and the spread between stops becomes Z travel
the machine is then obliged to have. Derivation alone would have made travel
*worse*.

So it is derived, but derived **once**: `STATION_TOOLING_HEIGHT = DECK_THICKNESS
+ STATION_MOUNT_T + max(STATION_PART_PASSAGE)`. Every station meets the ribbon on
that one plane. The difference between a part's own passage height and the plane
is taken up by a printed standoff under that part.

Two consequences worth recording:

1. **S6 drop and reject came down to the plane.** They previously sat 20 mm high
   to clear a bin rim — 20 mm of Z travel bought to solve a problem the chute
   solves for free. Put the chute *mouth* on the engagement plane and let the
   cable fall through it to a bin under the deck; the arm never lifts to drop.
2. **Z travel is now only what rotation clearance demands.** Required travel
   55 → 35 mm, and the stock stage drops 100 → 50 mm. Stiffness falls off with
   stroke, so this is the single cheapest stiffness improvement available, and it
   cost six printed standoffs weighing grams.

The guillotine's standoff computes to exactly 0.0 mm, which is the check that
the derivation closes: the part that sets the plane needs no packing.

Side effects: `DECK_ABOVE_BENCH` 170 → 174 mm (the deck rises as the tooling
stack shortens), and seven PLACEHOLDER dimensions became COMMITTED — 19/110 down
to 12/117.

**Also 2026-07-27 — `DECK_THICKNESS` corrected 10 → 12 mm.** layout.py carried
10 mm (an aluminium tooling plate from `cell-design.md`) while the generated cut
sheet quoted 1/2" ply. Two sources of truth for the one part that gets made on a
saw. `deck_cut_sheet.py` now reads the value instead of hard-coding it.

**2026-07-27 — The body clamp blocks the arm camera, and `camera_check` cannot
see it.** Found by trying to render the ribbon cycle from the arm's own camera —
the obvious viewpoint, since that camera exists precisely to watch the work
point. The body clamp fills the entire frame.

`camera_check` reports all six station tags in frame at 70 mm, 0.2° off-axis,
32.8° obliquity, and has done since it was written. It is not wrong; it answers
"is the tag within the field of view and at a sane angle" by geometry. It does
not answer "is anything in the way", because occlusion needs a render or a ray
cast, not a trigonometric check. A study that passes for the right reason and
still misses the problem is worth recording as carefully as a bug.

**Consequence:** the arm camera's job is step-readiness verification — did the
ribbon get gripped, did the slit cut, are three tails in three channels — and
it currently cannot see any of that. Either the camera moves, or the clamp does.
The camera is on the radial carriage and the clamp is on the wrist, so they move
independently; the fix is a placement study, not a redesign.

`camera_check` should grow an occlusion test before it is trusted again.

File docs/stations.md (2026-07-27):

# Stations S1–S3 — design, and what each demands of the arm

Phase 1 covers the ribbon-preparation half of the machine: feed, measure, cut,
slit, fan, strip. S4 (crimp) and S5 (insert) are out of scope and gated on
hardware that has not shipped.

**The reason these are designed now, before they are built:** the stations
define what the arm must reach, present, hold and resist. §4 collects those into
an arm specification — that is the real output of this document.

Dimensions live in `sim/layout.py`. Printed parts are generated by
`cad/build_parts.py`.

---

## 1. S1 — feed / measure / cut

The only station with a continuous material path, and the one P0 needs.

### Ribbon path

```
spool → dancer → drive rollers → encoder wheel → PTFE tube → presentation point
 110mm    passive    knurled +      independent    2mm ID       on the bolt
  OD      tension    polyurethane   of the drive                circle
```

### Parts

| Part | Spec | Notes |
|---|---|---|
| Spool | 110 mm OD, 31 mm wide, 8 mm bore, printed | Holds 17.9 m against a 15.24 m stock roll. Bore matches Z-stage rod stock |
| Hanger | 150 mm axle height, 3030 mount, printed | Gusseted — a bare 150 mm PLA upright flexes under dancer tension |
| Dancer arm | 70 mm, spring-loaded, printed | Constant light tension regardless of how the roll pays off. Its flag is the spool-empty detect |
| Drive rollers | knurled steel + polyurethane idler, spring preload, NEMA 17 | Pays out **and** pulls back |
| **Measuring wheel** | **31.83 mm dia = 100.00 mm circumference** | See below — this number is chosen, not inherited |
| Encoder | 600 P/R optical, quadrature | Independent of the drive |
| Guide tube | 2 mm ID / 4 mm OD PTFE, printed mount | Sets a repeatable presentation point regardless of spool behaviour |
| Guillotine | hardened blade + anvil, SDA20×20 | Square full-width cut |

### The measuring wheel diameter is a deliberate choice

**31.83 mm diameter gives exactly 100.00 mm of circumference.** With a 600 P/R
encoder in quadrature (2400 counts/rev) that is **0.0417 mm per count**, and
length in millimetres is just `counts × 100 / 2400` — no calibration constant to
get wrong, and two orders of magnitude finer than the ±0.5 mm we need.

Never measure length from drive-roller steps. Ribbon slips against a driven
roller under any tension change, and cable length is the one number the whole
machine is judged on. The encoder wheel rides the ribbon under light spring
preload and does no work, so it does not slip.

### Presentation gap

Tube exit to comb face at the grip position: **8 mm**. Long enough that the comb
never collides with the tube across Z and R tolerance; short enough that ~28 mm
of unsupported ribbon tail cannot buckle when the rollers push it out.

### Cut geometry

The guillotine blade must **shear, not crush**. A crushed ribbon end will not
enter the comb channels — which is the failure that stops the next cycle rather
than the current one, and therefore the expensive kind. Blade rake and a close
anvil clearance matter more than blade force here.

---

## 2. S2 — split + fan

**The ribbon is designed to be pulled apart by hand.** That is what flat
JR/Futaba servo wire is *for* — you zip the three conductors apart to terminate
them individually. Confirmed from the vendor spec, 2026-07-27.

That single fact reshapes this station. It was scoped as a precision
depth-adjustable two-blade slitting die, with depth control described as "the
whole game": too shallow and it will not zip, too deep and it nicks copper. But
if the web is deliberately weak, we are not cutting through insulation at all —
we are **starting a tear and then letting geometry propagate it.**

### Confirmed ribbon geometry (vendor spec, not measured, not guessed)

| | |
|---|---|
| Conductor OD | **1.40 mm** — listing states "Outer Diameter of Cable: 1.4mm" |
| Conductor pitch | **1.40 mm** — three conductors co-extruded tangent |
| Overall width | **4.20 mm** |
| Strands | 60 × 0.08 mm tinned copper = 0.302 mm² — genuine 22 AWG |
| Insulation | PVC |
| Mass | 250 g / 50 ft = 16.4 g/m |

`cell-design.md` gave the pitch as ~2.5 mm. That was the *connector* cavity
pitch borrowed by mistake, and it made this station look harder than it is —
webs at ±0.7 mm from centreline, not ±1.25 mm.

### Revised approach: splitting wedge, not slitting die

| | Original | Revised |
|---|---|---|
| Mechanism | 2 blades, depth-adjustable to 0.05 mm | Fixed splitting wedge, or a pull-apart pin pair |
| Critical control | Blade depth | Tear start and propagation length |
| Failure if wrong | Nicked copper → crimp fails a pull test two stations later | Split wanders or runs long |
| Actuator | Pneumatic cylinder, precise | Possibly none — the feed stroke can drive the ribbon onto a fixed wedge |
| Cost | ~$32 | Likely printed only |

**The wedge can be a fixed, printed part** that the ribbon is pushed onto by the
feed rollers, with the split length set by how far the arm advances rather than
by tooling geometry. If that works it removes a cylinder, a valve, two flow
controls, and the tightest tolerance in the station.

### What still genuinely needs the physical ribbon

Not the pitch — that is settled. Two things:

1. **Tear-start force and whether the split propagates straight** for 25 mm
   without wandering into a conductor. This is a materials behaviour, not a
   dimension, and no datasheet will answer it.
2. **Web thickness at the tangent**, which sets the wedge's leading-edge radius.
   Bounded by construction — it is thinner than the 1.40 mm conductor and thick
   enough to survive handling — but the exact value wants a caliper.

**Test it the moment the ribbon arrives, by hand, before designing tooling:**
zip 25 mm of it apart and watch what the tear does. Five seconds of work that
decides whether this station is a $32 pneumatic die or a printed wedge.

### Fan geometry

Split length 25 mm; outer conductors move `(8 − 1.40) / 2 = 3.30 mm` laterally
each, or `atan(3.30 / 25) = 7.5°`. Gentle — no set in the insulation, no mangled
breakout. **This answers open question 4 in `cell-design.md` §8.**

| Part | Spec | Notes |
|---|---|---|
| Splitting wedge | printed, leading edge on the web line | Replaces the two-blade die pending the hand test |
| Spreader plate | diverging slots, 1.40 → 8 mm over 25 mm, printed | 7.5° splay |
| Backing anvil | only if the wedge route fails | Deferred |

## 3. S3 — strip

| Part | Spec | Notes |
|---|---|---|
| V-blade die | 3 positions at 8 mm comb pitch | One stroke scores all three — equal strip length by construction |
| Depth shim | per recipe | Wrong depth = nicked strands = the crimp fails a pull test two stations later |
| Slug chute | printed | Three insulation slugs drop away, not into the mechanism |

Strip length is **2.75 mm** from the conductor tips. **The pull-off is done by
the arm retracting 4 mm** — there is no dedicated actuator, which is a saving,
but it puts a real requirement on the R axis (§4).

---

## 4. What the stations demand of the arm

This is the point of designing the stations early.

| Requirement | Value | Set by |
|---|---|---|
| θ stops | 7, over a 270° arc | Station count incl. separate reject |
| θ repeatability | better than ±0.2 mm at R₀ = **±0.057°** | Comb must re-find the same presentation point |
| Z travel | 55 mm | Spread of station engagement heights |
| Z per-station repeatability | ±0.1 mm | Slit and strip depth are set by die geometry, but Z error adds to it |
| R stroke | 80 mm | Retracted clearance to engaged |
| **R fine move** | **exactly 4.0 mm under load** | **S3 pull-off** |
| **R thrust** | **≥ 50 N** | Stripping 3 × 22 AWG at ~5–15 N each |
| S stroke | 20 mm, in 8 mm steps | Selects conductor 1/2/3 at comb pitch |
| W | 180°, two positions, hard stops | End B born opposite to end A |
| Body clamp | holds against 50 N axial | Must not let the ribbon slip during pull-off |
| Comb channels | guide, never grip | One conductor must advance independently |

### The two that constrain the design hardest

**R thrust of ~50 N.** Stripping three 22 AWG conductors simultaneously is the
largest force the arm ever applies. A NEMA 17 on a T8 leadscrew clears this
comfortably — a 2 mm lead gives a large mechanical advantage — but it rules out
a belt-driven R axis, which would need a much larger motor to hit the same
thrust without slipping teeth. **R is a leadscrew, and this is why.**

**The body clamp must not slip.** If the ribbon creeps in the clamp during
pull-off, strip length is wrong *and the measured cable length is wrong*, because
the ribbon has moved relative to the datum the encoder established. A slipping
clamp corrupts the machine's headline spec silently. Serrated pad, and worth
verifying with a pull test during commissioning.

### What the arm-mounted camera is and is not for here

Each station carries an AprilTag, so the camera measures actual pose versus
commanded at every stop — turning droop, detent error and belt backlash from
*assumed repeatable* into *measured and corrected*.

But tag pose at this working distance with a 3.6 mm lens is realistically
**±0.5–1 mm**. That is good for station registration, presence checks, and
verifying an operation happened (did the ribbon get gripped, did the slit cut,
are three tails in three channels). It is **not** a substitute for the
±0.057° mechanical repeatability above. Two different jobs.

---

## 5. Open

1. **Web thickness** between conductors — sets slit blade depth, and it is the
   single number S2 most depends on. Measure on arrival.
2. **Insulation pull-off force** for this specific ribbon — the 5–15 N per
   conductor above is a class estimate. Measure it, because it sizes the R axis
   and the body clamp together.
3. **Guillotine blade geometry** — rake angle and anvil clearance to shear
   rather than crush. Likely a trial-and-error item on scrap.
4. **Spreader entry geometry** — the funnel that gets a 1.45 mm-pitch tail into
   an 8 mm-pitch channel is the fiddliest printed part in Phase 1.

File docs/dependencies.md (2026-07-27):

# Dependencies

Every dependency in this project is here because someone asked for it explicitly
and it was justified in writing first. This file is that record.

**The rule:** nothing enters a package manifest without an explicit yes from
Kyle, preceded by a written proposal covering what it does, what drives the
need, what the alternatives were, and what it costs — transitive fan-out,
licence, platform coupling, footprint, maintenance status. Dev-only, build-only
and test-only dependencies get no exemption. Neither does "it's a tiny helper."

The default answer is **write it ourselves**. Small hand-rolled utilities cost
less than accumulated framework debt.

---

## Runtime — `pyproject.toml`

### `mujoco>=3.10`

| | |
|---|---|
| **What** | Physics simulation and rendering. |
| **Why** | The layout rough-in: reach, collision and cycle-closure studies. Kyle proposed it directly (2026-07-26) — TendWright already uses it, so the skills transfer. |
| **Licence** | Apache-2.0 |
| **Alternatives** | PyBullet was rejected on TendWright for being stale. Nothing else gives free contact simulation plus a usable viewer. |

### `numpy>=2.0`

| | |
|---|---|
| **What** | Array maths. |
| **Why** | MuJoCo's Python bindings hand back and take numpy arrays; it is effectively part of using MuJoCo at all. |
| **Licence** | BSD-3-Clause |

### `pillow>=12.3.0`

| | |
|---|---|
| **What** | Reads and writes image files, including saving a frame sequence as an animated GIF. |
| **Why** | Assembling `sim/run_cycle.py --frames` output into a single animated GIF of the arm cycle, for the README and for sharing progress. Plan 657.6. |
| **Authorised** | Kyle, 2026-07-26 |
| **Transitive fan-out** | **Zero.** Verified before install (`uv pip install --dry-run pillow` → 1 package) and again after, against the `uv.lock` diff. |
| **Licence** | MIT-CMU (HPND). Permissive; compatible with this repo's MIT + CC BY 4.0. |
| **Platform coupling** | None problematic. Compiled C extensions, but prebuilt wheels ship for Windows/macOS/Linux on all current Pythons — no source build. |
| **Footprint** | 6.9 MiB wheel. |
| **Maintenance** | Very active, near-monthly releases, among the most-downloaded packages on PyPI. |

**Alternatives considered, and why they lost:**

1. **Write a GIF89a encoder ourselves** — ~120–150 lines with LZW compression, and there was precedent: `sim/imaging.py`'s PNG writer started life hand-rolled. The killer was LZW. It is fiddly, and a subtly wrong encoder produces files that open in some viewers and not others — a miserable class of bug to chase for a convenience feature.
2. **An existing dependency** — no coverage. numpy cannot encode images; mujoco renders to arrays only.
3. **Skip the feature** — genuinely defensible, and it was offered as the honest second choice. The live viewer and the contact sheet already answer "show me the arm moving."
4. **ffmpeg → MP4** — better quality and smaller files, but a system binary rather than a Python dep, and MP4 does not inline in a GitHub README the way a GIF does.

**Net code impact:** roughly neutral. Pillow replaced the hand-written PNG
writer, and it enables text labels rendered into the contact sheet — previously
impossible, so reading order had to be explained in prose alongside the image.

---

## Tooling — not in any manifest

Installed on the machine, not depended on by the package. Listed so a fresh
setup knows what to install.

### FreeCAD 1.1.2

Parametric CAD. Generates every printed part in `cad/parts/` as a B-rep solid
and exports FCStd + STEP + STL. Also the route to dimensioned fabrication
drawings via TechDraw. Approved by Kyle 2026-07-26; installed per-user via
winget. Headless binary:

```
%LOCALAPPDATA%\Programs\FreeCAD 1.1\bin\freecadcmd.exe
```

Chosen over Onshape Free (all free-tier documents are public) and Fusion
Personal (licence churn). FreeCAD 1.0 fixed the topological naming problem that
made earlier versions unusable.

### poppler-utils

PDF rendering, so vendor datasheets can be read locally. This project consumes a
lot of them and two applicator drawings were unreadable without it. Approved by
Kyle 2026-07-26; installed via winget (`oschwartz10612.Poppler`).

### uv

Python environment and dependency management. Same tooling as TendWright.

---

## Not dependencies

Worth stating, because they look like they might be:

- **Blender** — used for renders and mockups, never imported by anything here.
- **The MuJoCo viewer** — ships with `mujoco`, not separate.
- **AprilTag detection** — `opencv-python` and `pupil-apriltags` are on
  **TendWright's** manifest, not this one. If CableCell grows its own vision
  code, that is a **new dependency conversation for this project**, not
  something inherited by proximity.

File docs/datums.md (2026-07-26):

# Datum scheme

**Status:** draft, revised 2026-07-26 for the base-mounted Z axis.

The first version of this document reported that the entire layout was blocked on
one unknown measurement. **The Z axis unblocks it** — see "What the Z axis
changed" below. This is now a working scheme with a small number of open
parameters rather than a stalled one.

---

## What this is

A **datum** is a reference that other dimensions are measured *from*. Choosing
them up front is what stops tolerances stacking and stops two stations being
designed to incompatible geometry.

---

## The three datums

### A — Deck plane

Top surface of the 10 mm tooling plate. **All heights (Z) are measured from
here.** Positive up.

Chosen because it is the one surface every station physically touches, and
because hole position in a tooling plate is repeatable in a way that shimming
never is.

### B — Pivot axis

The arm's rotation centerline, normal to Datum A. **All radii (R) and angles (θ)
are measured from here.** θ = 0 is assigned to S1 (feed/cut); positive θ is
counter-clockwise viewed from above.

The pivot axis is **carried by the Z stage** — it translates vertically but never
tilts. Datum B is therefore a line in plan view, fixed in X/Y, floating in Z.

### C — Station engagement heights (Z₁…Z₇)

*Formerly a single "work line" plane. Superseded by the Z axis.*

Each station has its **own** engagement height above Datum A — the Z the arm
moves to in order to present the ribbon to that station's tooling. Seven values,
held in configuration, established once by touching off at each station during
commissioning.

| | |
|---|---|
| Z₁…Z₇ | Per-station engagement heights (config, calibrated) |
| Z\_clear | Rotation-safe height — above the tallest station tooling intrusion |
| Z\_travel | Total stage stroke — must cover max(Zᵢ) − min(Zᵢ) plus clearance headroom |

**Z\_clear is the one that matters structurally.** With a Z axis, clearance during
rotation is achieved vertically (lift, rotate, descend) rather than radially
(retract to R\_safe). That decouples station tooling design from the arm's
rotation path — a station may now intrude inside the bolt circle, provided its
tooling stays below Z\_clear.

---

## The Z axis

**Configuration:** base → Z stage → rotary axis → arm. The Z stage carries the
entire rotating assembly (Kyle, 2026-07-26).

**Class:** commodity ballscrew linear stage — SFU1605 screw, SBR16 or MGN rails,
NEMA 17/23, ~0.03 mm positioning accuracy, 100–400 mm strokes, $62–200. Widely
available; not a custom build.

### 🔴 The coaxial conflict (found in the rough-in, 2026-07-26)

**A single commodity ballscrew module cannot carry this axis.** You cannot run a
rotary axis through the middle of a linear rail — and the rotary axis has to be at
the pivot, which is exactly where the rail wants to be. Visible immediately in
`sim/studies/renders/roughin_plan.png`: the Z column and the rotor compete for the
same space. This is the first thing the rough-in caught that prose had missed.

Three ways out:

| | Approach | Trade |
|---|---|---|
| **a** | Rotor cantilevered off one commodity module's carriage face | Cheapest, simplest to build. Hangs the whole assembly on a moment arm |
| **b** | Z platform on 3–4 vertical guide posts, driven by **one off-axis ballscrew** | Rotary axis sits at the platform centre, unobstructed. Stiffness from the post triangle rather than a cantilever. Still commodity parts, ~$150–250 |
| **c** | Move Z onto the arm rather than the base | No coaxial conflict at all, but adds moving mass at the end of the arm, fights the wrist for space, and gives up the station-tooling decoupling base-Z bought |

**OPEN, and deliberately gated on a measurement** — see below.

### The deflection budget is about variance, not strength

Corrected 2026-07-26 after Kyle pointed out how light the product is.

**The payload is negligible.** A 1.2 m length of 22 AWG 3-conductor ribbon at
1.4 mm OD is roughly **15–20 g**. The rotating assembly is on the order of
**2 kg**. The cable is about **1% of the moving mass** — not a factor in any load
calculation.

So the budget is not set by payload. It is set by:

1. **Self-weight** of the assembly cantilevered ~200 mm out — the dominant static
   load, and essentially *constant*.
2. **Arriving inside the insertion funnel's capture window.** Pencilled at
   ±0.3 mm, which at 200 mm reach is an angular budget of roughly **1.5 mrad
   (0.086°) across the entire stack** — Z carriage, rotary bearing, arm, radial
   slide, cross-slide. Z is one of five contributors.

This is a **precision** problem, not a strength problem, and that distinction
changes the architecture choice:

> **Repeatable sag is calibration, not error.** If the arm always droops the same
> 0.4 mm at a given θ/R/Z, it folds into the station Z table and the angular
> positions and costs nothing. With a ~20 g payload that never varies, that is
> exactly the regime we are in.

What defeats a cantilever is **non-repeatability** — backlash on direction
reversal, stick-slip in the bearings, thermal drift, play in the cross-slide and
wrist. Those do not calibrate out. Static droop does.

**So option (a) is far more viable than first assessed.** The architecture
decision waits on one number: **the funnel's real capture window**, which is the
headline output of de-risk B (plan 657.3) and needs nothing but printed parts and
housings.

- Funnel forgiving (±0.5 mm or better) → take the cantilever, option (a).
- Funnel tight (±0.15 mm) → the platform-on-posts earns its cost, option (b).

Cheaper to measure with $20 of PLA than to insure against with $150 of ballscrew.
**This makes 657.3 a prerequisite for the Z architecture, not just an experiment.**

### Other design constraints

- **Prefer the shortest Z travel that does the job.** Stiffness falls off with
  stroke, and travel is the parameter most likely to be over-specified "just in
  case." Currently 55 mm required → 100 mm stock stroke.
- Specify dual guidance, not a printer-class single-rod T8.

**Back-drive is a safety decision.** A trapezoidal leadscrew self-locks — cut
power and it holds. A ballscrew is efficient enough to **back-drive** under load,
so on a vertical axis carrying ~10 kg an E-stop could drop the arm. Resolve
deliberately: self-locking leadscrew (slower, less stiff, cheaper), or ballscrew
plus motor brake, or ballscrew plus counterbalance. **Open — see below.**

**Z couples to the ribbon path.** The ribbon runs from S1's fixed guide tube to
the comb; changing Z changes the free length between them. Irrelevant for
clearance moves on flexible servo ribbon, but the payout/measure step is
length-critical. Therefore: **the payout reference position includes a Z, and
payout only ever occurs at that Z.** One recipe constant; a silent length error
if omitted.

**Cable management.** The drag chain / service loop must now accommodate Z travel
in addition to the ±135° sweep.

**Homing order.** Z homes to its up position *before* θ is permitted to rotate,
or the arm can sweep into station tooling on power-up.

---

## The two derived numbers

### R₀ — bolt circle radius

Pivot axis to the station work point. Constrained from below by *angular fit* —
seven stops must share a 270° working arc, and the press is 210 mm wide against
a normal station's ~80 mm. Constrained from above by bench footprint and by arm
deflection under insertion load.

**Computed 2026-07-26 by `sim/studies/fit_check.py`:**

| R₀ | Press | Station | Needed | Spare | |
|---|---|---|---|---|---|
| 125 mm | 114.3° | 37.3° | 338.2° | −68.2° | ✗ |
| **150 mm** | 88.9° | 30.9° | **274.4°** | **−4.4°** | ✗ |
| 175 mm | 73.7° | 26.4° | 232.3° | +37.7° | ✓ |
| **200 mm** | 63.3° | 23.1° | **201.8°** | **+68.2°** | ✓ |
| 250 mm | 49.7° | 18.4° | 160.2° | +109.8° | ✓ |

🔴 **The ~300 mm bolt circle in `cell-design.md` does not close.** At R₀ = 150 mm
the seven stops need 274.4° of a 270° arc — short by 4.4°. That figure predates
understanding the press as a standalone 210 mm-wide machine, and it was never
checked against seven stops.

**Working value: R₀ = 200 mm** (400 mm bolt circle). Minimum viable is ~175 mm;
200 mm buys 68° of spare arc to absorb the station widths firming up, and keeps
the deck at a sane ~280 mm radius.

Still to confirm: that the arm can physically reach the anvil once
`PRESS_RAM_FROM_FRONT` is measured. Angular fit and radial reach are separate
constraints, and only the first is settled.

### θ₁…θ₇ — station angles

Seven stops, not six — S6 drop and the reject position are separate angles:

| Stop | Station | θ | Z |
|---|---|---|---|
| 1 | S1 feed / measure / cut | 0° (assigned) | Z₁ |
| 2 | S2 slit + fan | TBD | Z₂ |
| 3 | S3 strip | TBD | Z₃ |
| 4 | S4 crimp (press) | TBD | Z₄ |
| 5 | S5 insert | TBD | Z₅ |
| 6 | S6 drop — collect | TBD | Z₆ |
| 7 | S6 drop — reject | TBD | Z₇ |

Spacing is **not** uniform. Constraints: the arm sweeps a ~270° working arc (not
a full turn, so the trailing ribbon never wraps the pivot — no slip ring, no
rotary air union); the press occupies far more angular width than any other
station; and the press anchors θ₄ because it is placed first (see below).

---

## Press envelope (researched 2026-07-26)

Class: **1.5 T / 15 kN taped-terminal crimping press for mini applicators**, the
machine class BOM line 11 belongs to.

| Spec | Value | Source |
|---|---|---|
| Footprint | **210 × 210 mm** | vendor spec |
| Height | **580 mm** | vendor spec |
| Weight | **35 kg** | vendor spec |
| Stroke | **30 mm** (40 mm variants exist) | vendor spec |
| Motor | 0.55 kW | vendor spec |
| Supply | **AC 110/220 V, 50/60 Hz** | vendor spec |
| Applicators accepted | JST, Molex, TE mini applicators | vendor spec |
| Shut height | **not stated** | — |
| Throat depth | **not stated** | — |
| Base plate height above bench | **not stated** | — |

**Correction to an earlier estimate.** This document previously described the
press as "~300 × 250 × 500 mm and 30–50 kg." The mass was right; the footprint
was not. The real machine is a **narrow tall column press** — 210 mm square and
580 mm high. Footprint is roughly 40% smaller than assumed, which makes it
considerably more compatible with a ~300 mm bolt circle than feared. The
obstruction to design around is the **column**, not a wide base.

**110 V variants exist.** The voltage worry recorded on 2026-07-25 (step-up
transformers, 50 Hz motors running 20% fast on 60 Hz mains) is softened
substantially — this class is built in a 110 V/60 Hz configuration. Specify it at
purchase rather than solving it afterwards.

### Still needed, and where each comes from

| Number | Needed for | How we get it |
|---|---|---|
| Shut height (which standard) | Applicator compatibility, Z₄ | **Ask the seller** — question 5 on the 657.2 message |
| Throat depth (ram axis to column) | R₀, and whether the arm can reach the anvil | Ask seller, or measure on arrival |
| Base plate height above bench | Press mounting, deck relationship | Measure on arrival |
| Wire height above applicator base | **Z₄** | Measure on arrival — checklist item on 657.5 |

**Working assumption until measured:** the wire/anvil line sits low in the
applicator body, well under the 165 mm overall height of the OTP unit. Treat Z₄
as a **free parameter in `layout.py`** rather than a committed value. This is
exactly the case the Z axis was added to absorb — a wrong guess costs a config
edit, not a re-machined deck. Do not let a placeholder here harden into a
number anyone believes.

---

## Layout ordering: the press is the datum, not the dial

**Decided 2026-07-26 (Kyle).** A 1.5 T bench press is ~300 × 250 × 500 mm and
30–50 kg with a fixed vertical ram. It is not a bolt-on module in a sector; the
dial gets built around it.

Ordering:

1. Place the press. Its anvil position fixes **θ₄** and one point on the bolt
   circle; its crimp height fixes **Z₄**.
2. Place the pivot at R₀ from that point → fixes Datum B in X/Y.
3. Hang the other six stops off the resulting circle.
4. Calibrate Z₁…Z₃, Z₅…Z₇ at commissioning.

Note the Z axis makes step 1 much cheaper than it was: the press sets Z₄ only,
not a global height that all six other stations must be shimmed to match.

---

## Applicator shut-height fork (researched 2026-07-26)

Applicators mount to presses at a standardized **shut height** — base plate to
ram face at bottom dead centre. Two incompatible standards exist:

| Standard | Shut height | Who |
|---|---|---|
| Western industry standard | **135.78 mm** ±0.02 (5.345″) | Molex Mini-Mac, TE, Mecal EVS |
| Chinese OTP clone | **119.7 mm** | Kingsing, crimpapplicator.com, the eBay-class units |

A 16 mm mismatch — an applicator built to one will not run in a press built for
the other. Same class of trap as the AM-10: two things that both say "standard"
and mean different things.

**Sourcing consequence:** the applicator decision *leads* and the press follows.
Shut height is a fifth question on the seller message for BOM line 10, and the
answer constrains which press we buy.

**Layout consequence — now minor.** Pre-Z this was the root blocker of the whole
scheme. With Z it determines Z₄ and press mounting height only.

---

## Current values

| Symbol | Meaning | Value | Confidence |
|---|---|---|---|
| Z₁…Z₇ | Per-station engagement heights | config, calibrated | resolved by design |
| Z\_clear | Rotation-safe height | ~95 mm above deck | derived; moves with station tooling |
| Z\_travel | Z stage stroke | **55 mm needed → 100 mm stock stage** | computed 2026-07-26 |
| R₀ | Bolt circle radius | **200 mm** (min viable 175) | computed 2026-07-26 |
| Deck height above bench | Chosen to minimise Z travel | ~170 mm | derived from placeholder crimp height |
| θ₁ | S1 angle | 0° | assigned by definition |
| θ₂…θ₇ | Remaining station angles | unknown | arc now known to fit; spacing not assigned |

**The Z travel result is worth reading twice.** Only **55 mm** of stroke is
required, covered by the smallest useful stock ballscrew stage (100 mm). That is
a direct consequence of raising the deck ~170 mm above the bench to pull the six
short stations up near the press's fixed crimp height — at bench level the stage
would have had to span the whole difference. Short stroke means a stiff stage,
which lands straight in the comb deflection budget.

**Known independently, safe to model now:** comb 3 channels at 8 mm pitch ·
cross-slide stroke 20 mm · split 25 mm · strip 2.75 mm · insert depth 6 mm ·
pullback 1.5 mm · nest index 2.5 mm · cavity pitch 2.5 mm · main bearing
80–100 mm bore · MGN12 radial / MGN9 cross · 3030 frame · 10 mm deck · cable
length envelope 90–1000 mm · wrist 180°, two positions.

---

## Open questions

1. **Z travel spec.** What is max(Zᵢ) − min(Zᵢ) in practice, plus clearance
   headroom? Drives stage cost *and* stiffness. Wants the smallest defensible
   number. Blocked on press crimp height and station tooling heights.
2. **Ballscrew + brake, or self-locking leadscrew?** Decides whether an E-stop
   drops the arm.
3. ~~Is ~300 mm enough bolt circle?~~ **ANSWERED 2026-07-26: no.** R₀ = 200 mm
   (400 mm circle). See the fit table above.
4. **Where does the payout trough live?** It must control a dangling 1 m cable —
   larger than the entire dial. Probably off-deck, below or beside.
5. ~~Does 270° of arc fit seven stops?~~ **ANSWERED 2026-07-26: yes, at
   R₀ ≥ 175 mm**, not at 150 mm. 201.8° needed of 270° at the working R₀.
7. **Can the arm physically reach the anvil?** Angular fit is settled; radial
   reach is not. Blocked on measuring the press's ram-axis-from-front distance.
8. **Station angular spacing.** The arc fits, but θ₂…θ₇ are still an even spread
   rather than an assignment that respects the press's real angular footprint.
6. **Arm deflection budget.** Total compliance from Z carriage → rotary bearing →
   arm → radial slide → comb, under insertion load, versus the funnel capture
   window. Needs a number for the funnel first.

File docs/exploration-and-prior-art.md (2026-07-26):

# Cable-Making Robot Cell — Context Exploration + Implementation Thumbnail

**Date:** 2026-07-24
**Ask (Kyle):** A cell that is fed a spool of 2–3-conductor wire ribbon and, per cable: separates the conductors, strips them, crimps a pin on each, inserts the pins into a linear connector housing, pays out the ribbon to a requested length, then terminates the far end the same way. Output: a finished cable of length L with a connector on each end.

**Target part (pinned, from `TendWright/docs/wiring-hardware.md`):** **Molex Mini-SPOX 5264**, 3-position, **true 2.50 mm pitch** (not 2.54 — the Dupont/KK/XH lookalikes don't latch): housing **50-37-5033**, female crimp terminal **0008701039** (5263 series, 22–28 AWG, chain/reel form), on **22 AWG 3-conductor flat servo ribbon** (black/red/white = GND/Vcc/Signal). Both cable ends take the identical housing; this is the Feetech STS3215 servo-bus cable for the TendWright arm. See §2.7 for what this pins down.

---

## 1. What exists — the landscape

### 1.1 This machine class exists commercially (good news: proven decomposition)

The exact flow you described — ribbon in, split/strip/crimp both ends — is a shipping product category from the Chinese mid-market automation vendors:

- **Kingsing KS-T532** ("Automatic Ribbon Cable Stripping and Crimping Machine"): integrates *cut-to-length, stripping, conductor splitting, and dual-end terminal crimping* in one machine. AWG 18–28, cut length 60–1000 mm, strip 1–7 mm, ~400–550 cycles/hour, five servo axes, a mechanical-arm feed for length accuracy, independent terminal orientation per end, optional crimp-force monitoring. That is your spec minus housing insertion.
- **Kingsing housing-insertion line**: dual-head machines that add *housing insertion at both ends* on top of cut/strip/crimp, supporting single- and double-row housings, different housings per end, and crossed insertion patterns, with CCD vision for wire sequence checks.
- **JCWelec / WirePro / East World**: dedicated flat-ribbon slit-cut-strip machines (split length adjustable 0–60 mm per end, ribbon widths to ~20 mm), some with crimp + tin-solder stations.

Takeaway: nobody has to invent the process. The industry-standard station decomposition is **feed/measure → slit (split web) → strip → crimp → (insert) → cut**, done to the leading end first, then re-done to the trailing end after payout. These machines cost roughly $15k–60k; the interesting project is a benchtop DIY-scale version.

### 1.2 The industrial high end (architecture to steal, not buy)

- **Schleuniger CrimpCenter / Komax Zeta**: fully automatic cut-strip-crimp with wire feed up to 12 m/s and a **swivel arm** that presents the wire end to each fixed processing station in turn. Key architectural idea: *the wire end travels to the stations; the stations never move.* Zeta 620 does ~360 dual-ended cables/hour in a 2.1 × 1.5 m footprint.
- **Komax Omega 740/750**: adds fully automatic **block loading** (housing insertion) on both ends without interim wire storage. Insertion is: housing held in an indexed pallet, terminal pushed axially into the cavity until the housing lance clicks, then a **pull-back test** confirms retention.
- **Crimp applicator anatomy** (TE / ETCO / Mecal): the crimp itself is always a purchased **mini-applicator** — a self-contained tool that takes terminals on a bandolier reel, indexes one terminal per stroke via a cam-driven feed finger, and closes wire + insulation crimps over an anvil in a single ~40 mm press stroke (bench presses ~1.5–2 tonnes). The press is dumb; all the per-terminal intelligence lives in the applicator.

### 1.3 DIY / open-source state of the art

- Wire **cut + strip** is a solved hobby problem: many Arduino/stepper builds (Mr Innovative's cutter-stripper, sandy9159's GitHub project, Hackaday builds) — feed rollers + a movable blade that either scores (strip) or cuts through, ~$100 in parts.
- Automated **crimping** at hobby scale is essentially absent — the community stops at hand tools (Hackaday's "Inside the Secret World of Crimping" is the reference read). This is the hard station, and the reason to buy a real mini-applicator + small press rather than 3D-print one.
- Automated **housing insertion** at hobby scale: nothing found. This would be the genuinely novel part of the build.

### 1.4 The IDC counterpoint (worth one paragraph of honesty)

Ribbon cable's native termination is **IDC** — press a connector onto the *unstripped* ribbon; all conductors terminate simultaneously, no separate/strip/crimp/insert at all. An IDC-press station would collapse stations 2–5 into one pneumatic squeeze and is how industry handles ribbon whenever it can. **For our pinned target it doesn't apply:** Mini-SPOX 5264 is a crimp-only system (no IDC variant), and 22 AWG servo ribbon isn't IDC stock anyway — so the full crimp-and-insert cell below is genuinely required. Noted for honesty, closed as not applicable.

---

## 2. Thumbnail: benchtop cable cell v0

### 2.1 Concept in one sentence

A linear benchtop machine (~900 × 400 mm) where the ribbon stays stationary and a small **end-effector shuttle** carries the ribbon end through five fixed stations — slit, strip, crimp, insert — once for the leading end, then pays out length L, cuts, and repeats the sequence on the trailing end with the ribbon flipped 180° by the shuttle's rotary wrist.

```
 spool ──> dancer ──> feed rollers ──> [SHUTTLE zone] ──> guillotine ──> exit tray
 (A)       (B)        (C, encoder)          │              (G)
                                            │ shuttle gripper w/ 180° wrist (D)
                                            ▼ visits, in order:
                              ┌──────────────────────────────┐
                              │ S1 slitter  (web knife)      │
                              │ S2 stripper (V-blades + pull)│
                              │ S3 crimp    (mini-applicator │
                              │              + servo press)  │
                              │ S4 insert   (housing nest +  │
                              │              pusher + pull   │
                              │              -back check)    │
                              └──────────────────────────────┘
```

### 2.2 Stations

**A. Spool + dancer.** Passive payoff with a spring dancer arm for constant light tension; a flag sensor for "spool empty."

**B/C. Feed + measure.** Pinch rollers on a NEMA17 with an independent measuring-wheel encoder (don't trust roller steps — ribbon slips). This axis owns cable length accuracy; ±1 mm over 1 m is achievable, matching commercial ±(0.5 + 0.2 %·L) mm specs.

**D. Shuttle.** The one real robot in the cell: a linear axis (~300 mm) along the station row, a gripper that clamps the ribbon ~30 mm behind the working end, a small vertical axis, and a 180° rotary wrist. The wrist is what makes double-ended work possible: for the trailing end the ribbon is flipped so the same stations, same geometry, treat it identically. (This mirrors the CrimpCenter swivel-arm philosophy: stations fixed, wire end moves.)

**E — S1. Slitter.** For bonded ribbon, a heated or plain razor blade in a slot die notches the web between conductors for the last ~25 mm; then a spreader comb fans the 2–3 now-free tails into a fixed 2.54 mm-pitch (or wider, see 2.4) guide. Split length adjustable exactly like the commercial 0–60 mm spec.

**F — S2. Stripper.** Classic V-blade pair on a small stepper closes to a gauge-specific depth, then the *shuttle* pulls back ~3–5 mm to slip the insulation. One conductor at a time (shuttle steps across the pitch), or all-at-once with a multi-V blade comb if the pitch is fixed. Strip length 2–3 mm for 2.54 mm pins.

**G — S3. Crimp.** **Buy, don't build:** a genuine mini-applicator for the chosen terminal (SXH / KK 2759 / Dupont-clone bandolier reels are cheap) driven by a servo ballscrew press (~2 t) or a compact pneumatic press. Terminal feed, alignment, and crimp form all come free with the applicator. The shuttle presents one stripped conductor per stroke, stepping across the row. Add a load cell for crude crimp-force monitoring — that's the standard QA signal.

**H — S4. Insertion.** The novel station. Housing feed first: unlike the terminals (bandolier reel), **5264 housings ship loose in a bag** — there is no engineered feed form. Commercial block loaders solve this with a vibratory bowl + linear track that orients and singulates them; that's tuning-intensive overkill at benchtop scale. v1 answer (confirmed by Kyle 2026-07-24): a **hand-loaded 3D-printed stick magazine** — a vertical channel whose cross-section matches the housing profile so it only fits one way (the friction-lock ramp keys orientation), gravity- or spring-fed, with a simple escapement (sliding shuttle plate) that drops exactly one housing into the nest per cycle. Loading ~25 housings takes under a minute of operator time and covers ~12 cables; a low-stack sensor gives warning. The magazine is a swappable printed cartridge — one per housing type, which is exactly the right seam for the "other connectors later" roadmap. (Upgrade path if hand-loading ever becomes the bottleneck: mini vibratory bowl, the commercial answer.) From there the nest sits on a small indexing axis that positions cavity *i* on the machine centerline. Sequence per pin: shuttle aligns pin to cavity mouth (a tapered guide funnel forgives ~±0.3 mm), pushes axially ~6 mm until the housing lance clicks, then pulls back 1–2 mm against a stop — the **pull-back retention test**, the single most valuable QA step in commercial block loading. Insert order: outermost cavity first so already-inserted wires don't shadow the funnel.

**I — Guillotine.** Full-width shear that separates the finished cable *after* the trailing end has been processed (order of operations below). Finished cable drops to a tray.

### 2.3 Process order (one cable)

1. Feed ribbon leading end to shuttle; shuttle grips.
2. Leading end: slit → strip → crimp ×N → insert ×N (this end is now "connectorized," hanging from the shuttle).
3. Shuttle releases; feed rollers pay out length L (encoder-verified) past the guillotine.
4. Shuttle re-grips at the guillotine side; guillotine cuts. The cut creates two ends: the **trailing end of the finished cable** (in the shuttle, flipped 180° by the wrist) and the **new leading end of the spool** (parked).
5. Trailing end: slit → strip → crimp ×N → insert ×N → drop finished cable.
6. Next cable starts at step 1 with the already-cut new leading end — zero waste between cables.

This is exactly the commercial dual-end sequencing, and it means cycle time ≈ 2 × (end-treatment time) + payout. With ~4 s per pin across strip/crimp/insert and 3 pins/end, a ~60–90 s cable is realistic for v0 (commercial: ~7–9 s).

### 2.4 The three hard problems, ranked

1. **Crimp quality** — solved by purchasing the mini-applicator; do not attempt DIY crimp tooling, this is where every hobby attempt dies. Budget item, ~$300–800 used/clone per terminal type.
2. **Insertion reliability** — pin tip position after crimping varies; the funnel guide + compliant gripper (slight lateral float) + pull-back test is the mitigation stack. Expect this to be 60 % of the debugging hours.
3. **Ribbon slitting without nicking conductors** — blade depth control to ~0.1 mm; a shaped slot die per ribbon geometry makes it repeatable. Pre-scored/"zippable" ribbon (or discrete-wire bonded pairs) makes this station nearly trivial — worth choosing the wire stock around.

### 2.5 Control + rough BOM

Control: one motion controller (grbl-HAL / Klipper on a Pi, or a Duet) — 6–7 stepper axes (feed, shuttle X/Z, wrist, housing index, stripper blades, press if servo), ~10 sensors (encoder, blade home switches, terminal-out, housing-out, spool-out, load cell), pneumatics optional. UI: enter L and quantity — same contract as the hobby wire-cutter builds.

| Block | Est. cost |
|---|---|
| Frame, rails, 3D-printed stations | $250 |
| Steppers/drivers/controller/PSU | $300 |
| Mini-applicator + terminal reels | $300–800 |
| Press (servo ballscrew or air) | $200–400 |
| Blades, slot die, guillotine | $100 |
| Housing magazine + nest | $50 (printed) |
| Sensors, encoder, load cell | $100 |
| **Total** | **~$1.3–2k** |

### 2.6 Suggested build path (de-risk order)

1. **Bench-validate S3**: press + applicator crimping hand-fed stripped ribbon tails — proves the money station.
2. **S4 prototype**: hand-crimped pigtails inserted by a manual-jig version of the funnel/pusher/pull-back — proves the novel station before any motion control exists.
3. Feed/measure/cut module (known-solved hobby territory).
4. Slit + strip stations.
5. Shuttle + wrist, integrate, then the state machine for dual-end sequencing.

Steps 1–2 together are a weekend-scale experiment and would retire most of the project risk before committing to the full frame.

### 2.2b Rotary architecture (Kyle 2026-07-24 — adopted over the linear sketch)

**"Shuttle and stations," restated plainly.** A *station* is a fixed piece of tooling that does one operation and never moves from its spot (blade, strip jaws, crimp press, housing nest). The *shuttle* is the one thing that moves the workpiece: it holds the ribbon end and carries it to each station in turn. The alternative — moving four tool heads to a stationary wire — needs four times the motion hardware, which is why every commercial machine moves the wire instead (Schleuniger's swivel arm, Komax's transfer arms).

**Kyle's version: put the stations on a bolt circle, not in a line.** The shuttle becomes a pivot arm that indexes rotationally between station sectors and *extends radially* into whichever station it's facing. This is the classic **dial / rotary indexing machine**, and it beats the linear sketch on three counts:

- **Two axes instead of two, but better ones.** Rotary index + radial extend. A rotary index can drop into hard detents at each station, so repeatability comes from mechanical stops rather than from a long linear rail staying square.
- **Stations become bolt-on modules.** Each occupies a sector; adding, removing, or swapping one is a bracket change. That is *exactly* the seam the "other connectors later" roadmap needs — a new connector family becomes a new insert-station sector plus a new magazine cartridge.
- **Compact.** A ~300 mm circle holds five stations in less bench space than a 900 mm rail.

**Station sectors (working arc, not a full turn):** feed/cut → slit → strip → crimp → insert, plus a **park** position where the finished end A waits during payout. Keep the arm inside a ~200–270° arc so the trailing ribbon sweeps but never wraps the pivot. (Full 360° is only safe if the ribbon feeds through the rotation center — and twisting 3-conductor ribbon is not worth it.) The **feed/cut sector is a station like any other**: feed rollers pay out length L there, the guillotine lives there, and it's where the arm picks up each new end.

### 2.2c The per-pin problem — and the trick that dissolves it

Kyle's instinct is correct: **crimp and insert are inherently one-conductor-at-a-time operations.** The applicator crimps one terminal per stroke; each pin goes into its own cavity. This is not a weakness of our design — the industrial block loaders do exactly this, one lead at a time (the foundational patent is literally titled *"Single lead insertion connector block loading apparatus"*). So we're in good company. The question is only *what moves* to make it happen.

**The gripper is a 3-slot comb, not a clamp.** Each conductor sits in its own channel. That one change turns "handle a floppy trio" into "handle three individually addressable conductors," and it is what makes per-pin work tractable.

**At the crimp station — move the ribbon, index the conductor.** Add a small lateral **cross-slide** to the arm (one cheap axis). Present conductor 1 to the anvil, crimp, shift one pitch, present conductor 2, crimp, shift, conductor 3. The applicator never moves. This directly answers Q2's collision worry: the fan pitch at the crimp station is set by the comb, **not** by the 2.5 mm connector pitch — spread the conductors as wide as the split length allows (10–15 mm is free), and finished pins simply aren't near the applicator throat when the next conductor arrives.

**At the insert station — move the housing, not the wires.** This is the key move, and it resolves the awkward part. Naive version: insert conductor 1, then shift the comb to bring conductor 2 over — but conductor 1 is now anchored in the housing, so shifting strains or backs out the pin you just placed. Invert it:

> **The insertion axis is fixed. The housing nest indexes one pitch per pin. The comb releases one conductor at a time.**

Insert conductor 1 into cavity 1 on the fixed insertion line; release it from the comb; index the *nest* one pitch so cavity 2 arrives on that same line; feed conductor 2; repeat. Already-inserted conductors travel **with their housing**, so they're never strained — the geometry stays identical for every pin, and the funnel/pusher tooling only ever has to work at one spot.

**What pushes.** Never the pin itself — a pin must not be loaded through its crimp. A small pusher finger closes on the **wire ~5 mm behind the pin** and drives it forward until the housing lance clicks, then pulls back against a stop for the retention test.

**Resulting motion budget (rotary architecture):**

| Motion | Type | Notes |
|---|---|---|
| Arm rotary index | stepper/servo | detents at each station sector |
| Arm radial extend | stepper/servo | shared by every station — the big win |
| Comb cross-slide (conductor select) | stepper | serves both crimp indexing and insert feeding |
| Ribbon feed / payout | stepper + encoder wheel | owns cable length accuracy |
| Housing nest index | stepper | one pitch per pin |
| Comb jaws, slitter, strip jaws, guillotine, crimp press, insert pusher | **pneumatic** | on/off actuators — cheap, strong, and Kyle's already going air for the press |

Five motion axes, six air cylinders. That is a very buildable machine, and the pneumatic column is why the compressor turns out to be load-bearing rather than incidental.

**Status:** this supersedes the linear layout in §2.2. Q1 is answered (rotary arm + comb + cross-slide); Q2 is answered in principle by decoupling fan pitch from connector pitch, and still wants the printed mockup before anything is machined.

### 2.6b Maturity check — what this document is and isn't

**Settled (high confidence):** the process decomposition and its order; that it's buildable at benchtop scale; the target part and everything it constrains; buy-the-crimp-tooling; hand-loaded printed housing cartridge; dual-end via 180° flip. These are validated against shipping commercial machines and are unlikely to change.

**Thumbnail-grade (mechanism kinematics):** everything about *how one gripper presents a bonded trio of conductors to four stations* is drawn at the level of "and then the shuttle does it." That's where the real engineering hours are. The open questions below are not nitpicks — Q1 and Q2 could force an architecture change.
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

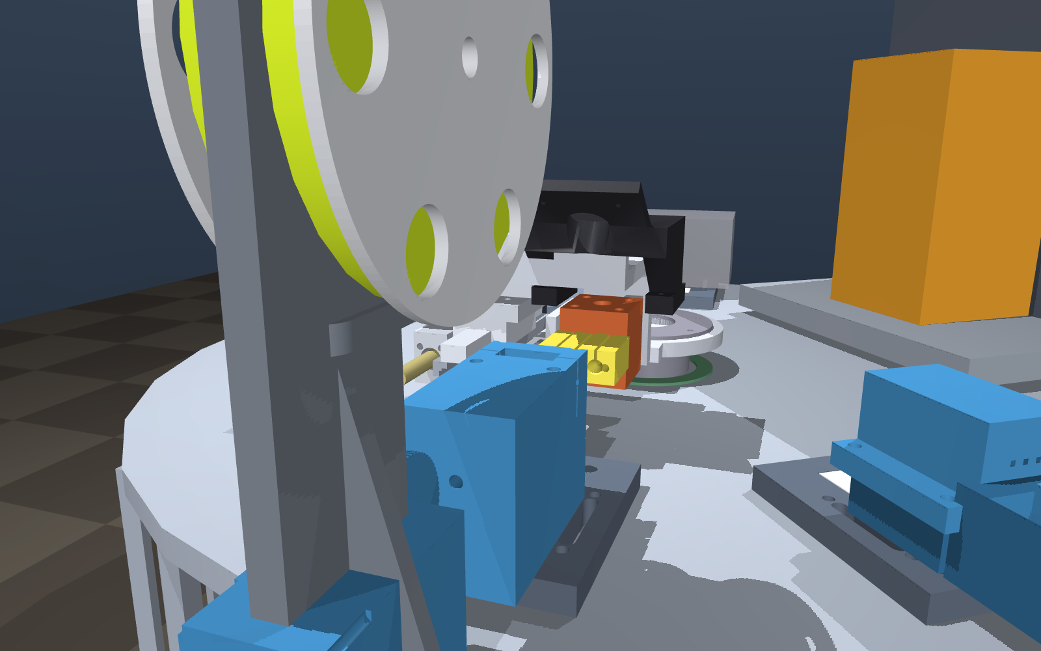
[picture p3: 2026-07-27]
sim/studies/renders/arm_drive.png

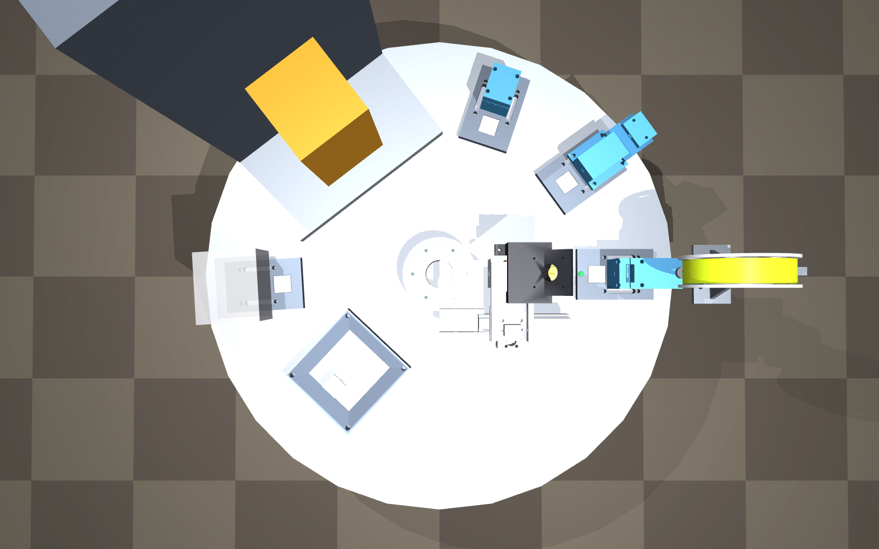
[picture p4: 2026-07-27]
sim/studies/renders/roughin_plan.png

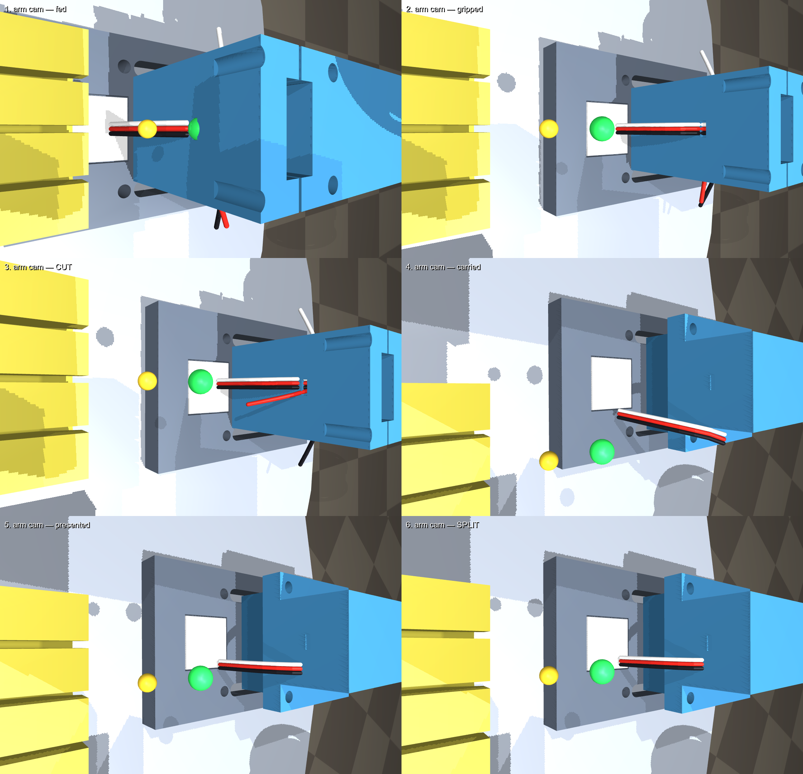
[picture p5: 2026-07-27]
sim/studies/renders/ribbon_cycle_armcam.png

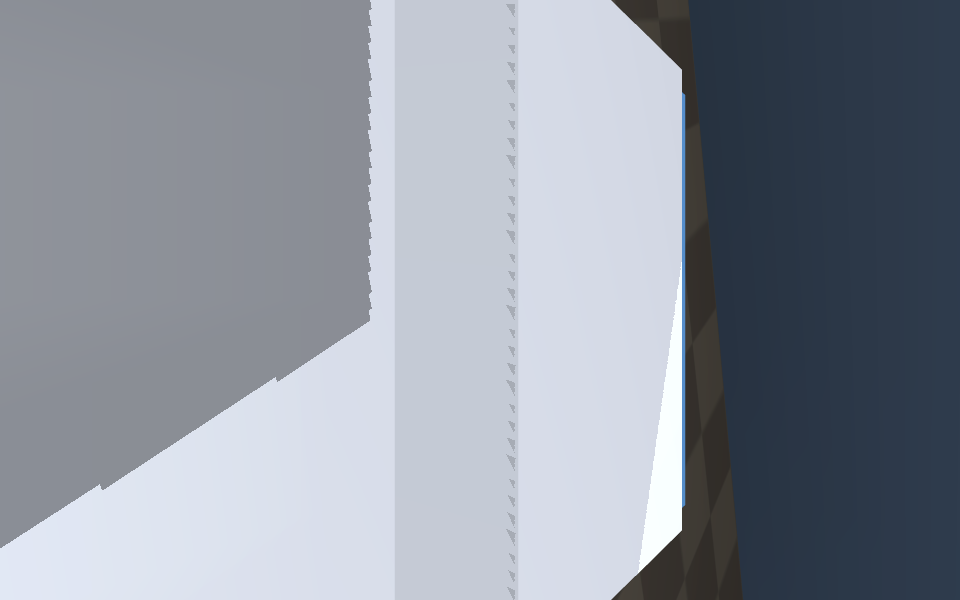
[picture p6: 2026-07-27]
sim/studies/renders/arm_cam/s3_strip.png

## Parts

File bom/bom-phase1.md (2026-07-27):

# Phase 1 BOM — motion system + ribbon prep

**Plan:** 657.6 · **Scope:** the arm (Z, θ, R, S, W) plus S1 feed/measure/cut,
S2 slit/fan, S3 strip. Crimp and insert are out of scope.

**Nothing here is ordered.** This is a buy list; clicking is Kyle's.

**Live sourcing pass 2026-07-27** in Kyle's logged-in Chrome session. Per the
`source-bom` skill, every line carries a verification mark:

- ✅ price read off the live product page, dated
- ⚠️ product class confirmed live, exact variant not pinned
- ⓘ **unsourced** — a planning figure, explicitly not a price

Sourcing rationale per category is in [`docs/sourcing-index.md`](../docs/sourcing-index.md).

---

## 0. Totals

| Module | Cost | Sourced |
|---|---|---|
| §1 Cell infrastructure | ~$239 | 6 of 8 ✅ |
| §2 Pneumatics | ~$359 | 10 of 12 ✅ |
| §3 Main arm | ~$222 | 7 of 9 ✅ |
| §4 Station 1 — feed / measure / cut | ~$65 | 3 of 6 ✅ |
| §5 Station 2 — split + fan | **$0–32** | printed; fallback only if wedge fails |
| §6 Station 3 — strip | ~$32 | 1 of 2 ✅ |
| §7 Printed parts — filament | **$28** | 2 of 2 ✅ |
| §7c Consumables — ribbon, reference cables | **$28** | 4 of 4 ✅ |
| §7b Arm camera | ~$20 | camera owned |
| **Phase 1 total** | **~$993–1,025** | **~33 of 46 lines priced live** |

Roughly **83% of the cost** now sits on lines priced off a real page, up from
about 20% before this pass. The remaining ⓘ lines are small consumables plus the
two station tooling sections, which depend on geometry not yet fixed.

**Biggest correction: the motion controller was estimated at ~$110 and is
$53.99** — 2× high, in the *opposite* direction to the slew-ring miss which was
5× low. Guesses err both ways. That is the argument for not making them.

Excluded because already owned or on `bom-v1.md`: NUC supervisor ($0), the ribbon
($9.30 ×2), the arm camera (Kyle has spares).

---

## 1. Cell infrastructure

| # | Item | Pick | Price | Qty | Notes |
|---|---|---|---|---|---|
| 1.1 | Motion controller | [BTT Octopus V1.1](https://www.amazon.com/dp/B094Y77FQN) `B094Y77FQN` | ✅ **$53.99** | 1 | 8 driver slots for 6 axes. Spare **heater/fan MOSFET outputs drive the solenoid valves** — see §2 |
| 1.2 | Stepper drivers | [BTT TMC2209 pack](https://www.amazon.com/dp/B07ZQ3C1XW) `B07ZQ3C1XW` | ✅ **$26.99** | 2 | 6 axes; two packs |
| 1.3 | 24 V / 350 W PSU | [MEAN WELL LRS-350-24](https://www.amazon.com/dp/B07VRK86SP) `B07VRK86SP` | ✅ **$35.97** | 1 | Steppers, valve coils, sensors |
| 1.4 | 3030 extrusion, 500 mm ×4 | [3030 T-slot 4-pack](https://www.amazon.com/dp/B0DP28NX2D) `B0DP28NX2D` | ✅ **$39.99** | 1 | Frame and deck supports |
| 1.5 | Extrusion hardware | corner brackets, T-nuts, M5 cap screws | ⓘ ~$30 | 1 | **Unsourced** — depends on the frame design |
| 1.6 | Deck plate | **Kyle supplies and cuts.** 1/2" plywood, **22-1/16" OD**, 7" centre hole, 15-3/4" bolt circle | **$0** | 1 | Full imperial spec + drilling template: [`docs/deck-cut-sheet.md`](../docs/deck-cut-sheet.md). Deliberately *not* aluminium tooling plate — see §8 |
| 1.7 | E-stop, hard-wired | [22 mm mushroom, 1NC latching](https://www.amazon.com/dp/B09YD2PNC5) `B09YD2PNC5` | ✅ **$8.99** | 1 | Cuts 24 V to motors and valves directly, not via software |
| 1.8 | Drag chain | [10×20 mm, 1 m open type](https://www.amazon.com/dp/B0BGKC1BPZ) `B0BGKC1BPZ` | ✅ **$12.99** | 1 | Must take the ±135° sweep **and** the Z stroke |
| 1.9 | Wiring, connectors, ferrules | 18–22 AWG, JST-XH, heatshrink | ⓘ ~$30 | 1 | **Unsourced** |

**Subtotal ~$239** · 6 of 8 priced live (deck supplied by Kyle)

---

## 2. Pneumatics

The chain per actuator is **cylinder → flow controls → solenoid valve (on a
shared manifold) → MOSFET output**. The cylinder has no electrical connection;
the valve is what the controller talks to.

| # | Item | Pick | Price | Qty | Notes |
|---|---|---|---|---|---|
| 2.1 | Compressor | [California Air Tools 1P1060S](https://www.amazon.com/dp/B01LYHYHEA) `B01LYHYHEA` | ✅ **$149.00** *(07-25)* | 1 | 56 dBA, oil-free, 1 gal, 1.20 CFM @ 90 psi |
| 2.2 | Filter + regulator | [NANPU 1/4" NPT](https://www.amazon.com/dp/B07TPCGWPY) `B07TPCGWPY` | ✅ **$15.99** *(07-25)* | 1 | **Deliberately not a full FRL** — a lubricator injects oil into the air, the last thing we want near crimp tooling |
| 2.3 | Valve manifold, 6 station | [US Solid 4V210-08 ×6 + base, 24 V](https://www.amazon.com/dp/B098NMSZ6Z) `B098NMSZ6Z` | ⚠️ ~$58 | 1 | 5/2, 24 VDC. Anchors: 4-station $37.56, 8-station $80.30 |
| 2.4 | Cylinder — body clamp | [Baomain SDA16×10](https://www.amazon.com/dp/B01LLQ6GEK) `B01LLQ6GEK` | ✅ **$7.99** | 1 | On the arm; clamps the unsplit ribbon behind the comb |
| 2.5 | Cylinder — guillotine | [Baomain SDA20×20](https://www.amazon.com/dp/B01LMMXDXA) `B01LMMXDXA` | ✅ **$11.47** | 1 | Needs the most force of the five |
| 2.6 | Cylinder — slit blades | Baomain SDA20×20 `B01LMMXDXA` | ✅ **$11.47** | 1 | |
| 2.7 | Cylinder — spreader | Baomain SDA16 class | ⚠️ ~$8 | 1 | 16×20 variant, same family as 2.4 |
| 2.8 | Cylinder — strip blades | Baomain SDA20×20 `B01LMMXDXA` | ✅ **$11.47** | 1 | |
| 2.9 | Flow controls (meter-out) | [10 pc, 6 mm × M5 push-to-connect](https://www.amazon.com/dp/B0G4BWS1HK) `B0G4BWS1HK` | ✅ **$13.49** | 1 | **Two per cylinder, not optional.** Without them cylinders slam at full line pressure — fatal to slit-depth repeatability |
| 2.10 | Reed switches | [Baomain cylinder magnetic sensor](https://www.amazon.com/dp/B01IZAFRWC) `B01IZAFRWC` | ✅ **$8.29** ea | 4 | Extended + retracted confirmation. Turns "fire and hope" into "fire and confirm" — required before the arm may rotate away from a die |
| 2.11 | Tubing | [TAILONZ 6 mm OD PU, 10 m](https://www.amazon.com/dp/B0DM1YWDTR) `B0DM1YWDTR` | ✅ **$18.99** | 1 | |
| 2.12 | Air pressure switch | [QWORK 90–120 psi](https://www.amazon.com/dp/B08FBCDNR5) `B08FBCDNR5` | ✅ **$19.97** | 1 | Refuse to run on low air — a half-stroke die is worse than no stroke |

**Subtotal ~$359** · 10 of 12 priced live

**Wiring note:** valve coils draw ~170–330 mA at 24 V — far past a logic pin.
Drive from the Octopus's MOSFET outputs. **Flyback protection is mandatory:**
either DIN 43650 connectors with surge suppression, or a diode across each coil.
Skipping it kills outputs.

---

## 3. Main arm

Five axes: **Z** lift, **θ** rotate, **R** extend, **S** cross-slide, **W** wrist.

| # | Item | Pick | Price | Qty | Notes |
|---|---|---|---|---|---|
| 3.1 | Steppers | [NEMA 17 42×40, 0.41 N·m, 1.5 A](https://www.amazon.com/dp/B0FHHVPJF1) `B0FHHVPJF1` | ✅ **$14.84** ea | 6 | Z, θ, R, S, W, F(feed). 5.0★ |
| 3.2 | **θ spindle bearings** | [uxcell 6810-2RS 8-pack](https://www.amazon.com/dp/B0H1LVWD99) `B0H1LVWD99` | ✅ **$26.99** | 1 | **$3.37 each** — the 8-pack beats [VXB's $24.99 singles](https://vxb.com/search?q=6810) by 7×. Paired 50 mm apart: 240 N radial each vs ~6,200 N static, **26× margin** |
| 3.3 | Z stage — guide rods | 8 mm hardened rod, 200 mm | ⓘ ~$14 | 3 | **Unsourced** |
| 3.4 | Z stage — linear bearings | [LM8UU 12-pack](https://www.amazon.com/dp/B0F1YGLS8X) `B0F1YGLS8X` | ✅ **$10.99** | 1 | Two per post, plenty spare |
| 3.5 | Leadscrews | [T8 200 mm + brass nut](https://www.amazon.com/dp/B07B63CVSJ) `B07B63CVSJ` | ✅ **$8.19** ea | 3 | Z, R, S. **T8 trapezoidal self-locks** — an E-stop will not drop the arm |
| 3.6 | θ — belt reduction | [GT2 20T + 60T + belt](https://www.amazon.com/dp/B0D5HMMGKG) `B0D5HMMGKG` | ✅ **$9.99** | 1 | 3:1. Resolution and holding torque against station reaction |
| 3.7 | R — linear rail | [MGN12H 250 mm + carriage](https://www.amazon.com/dp/B0BYV8SYPG) `B0BYV8SYPG` | ✅ **$17.99** | 1 | The shared "extend into the station" motion |
| 3.8 | S — cross-slide rail | [uxcell MGN9 100 mm + MGN9C](https://www.amazon.com/dp/B0D54LNVKX) `B0D54LNVKX` | ✅ **$9.99** | 1 | 20 mm stroke, selects conductor 1/2/3 |
| 3.9 | Couplers, collars | 5×8 flexible couplers, shaft collars | ⓘ ~$18 | 1 | **Unsourced** |

**Subtotal ~$222** · 7 of 9 priced live

### 💡 Worth pricing before ordering: integrated leadscrew motors

The pass surfaced [NEMA 17 with an **integrated T8 leadscrew shaft**, 150 mm,
0.4 N·m, **$14.38**](https://www.amazon.com/dp/B0CX8Z2MGT) `B0CX8Z2MGT` — the same
price as a plain motor. For Z, R and S that replaces *motor + coupler + separate
screw* with one part, removing an alignment error source and improving
concentricity. Could take ~$30 out **and** simplify three axes. Check the
available lengths against our strokes first.

### 🔴 A lazy-susan turntable was proposed here and withdrawn

Rated for **axial** load on a table, not moment. Under a 200 mm cantilever they
tip, and their millimetre-scale axial play would have invalidated the very
stiffness test that justifies building Phase 1 at the full R₀. **Do not buy one.**

The paired spindle is plausibly the **production** answer too, not a stand-in —
better per dollar than a slew ring for this load case, and it shrank the Z
platform from 248 mm to 165 mm.

### Slew-ring fallback, if the spindle shows runout

Bore and OD are **not independent** — PBC catalogue, 2026-07-26:

| bore | OD | cheapest |
|---|---|---|
| 20 mm | 80 mm | $93.69 |
| 30 mm | 100 mm | $127.23 |
| 50 mm | 150 mm | $164.19 |
| 60 mm | 160 mm | $199.35 |
| 100 mm | **185 mm** | $289.65 |

A 100 mm bore comes with a 185 mm OD, not the 120 mm once assumed. That ripples
into the Z platform, which is why `Z_POST_CIRCLE_R` is **derived** in `layout.py`
rather than hand-set — typing it by hand caused two clashes.

---

## 4. Station 1 — feed / measure / cut

| # | Item | Pick | Price | Qty | Notes |
|---|---|---|---|---|---|
| 4.1 | Spool | printed, 110 mm OD, 8 mm bore | — | 1 | **The ribbon ships as a loose roll**, so hub, flange and bore are ours. Holds 17.9 m vs a 15.24 m stock roll |
| 4.2 | Hanger + dancer arm | printed | — | 1 | Passive payoff; the dancer flag doubles as spool-empty detect |
| 4.3 | Dancer spring | extension spring assortment | ⓘ ~$8 | 1 | Also on `bom-v1.md` line 7 |
| 4.4 | **Measuring encoder** | [600 P/R incremental optical, 5–24 V](https://www.amazon.com/dp/B0G52C5BW1) `B0G52C5BW1` | ✅ **$14.99** | 1 | **Owns cable length accuracy.** With the wheel below: **0.0417 mm/count** |
| 4.5 | Measuring wheel | printed, **Ø31.83 mm = 100.00 mm circumference** | — | 1 | Length in mm is `counts × 100 / 2400`. **No rubber tyre** — a compliant surface changes effective circumference, the exact error this wheel exists to avoid |
| 4.6 | Drive rollers | knurled shaft + polyurethane idler | ⓘ ~$15 | 1 | **Unsourced** — printed housing exists (`drive_roller_block`) |
| 4.7 | PTFE guide tube | [Quickun 2 mm ID / 4 mm OD](https://www.amazon.com/dp/B08Q7X1J2Z) `B08Q7X1J2Z` | ✅ **$6.99** | 1 | Sets a repeatable presentation point regardless of spool behaviour |
| 4.8 | Guillotine blade | replaceable chisel/utility blade | ⓘ ~$10 | 1 | **Unsourced.** Must **shear, not crush** — a crushed end will not enter the comb channels |
| 4.9 | Spool-empty sensor | [IR slot/photo-interrupter modules](https://www.amazon.com/dp/B0CHDRF497) `B0CHDRF497` | ✅ **$9.99** | 1 | Reads the dancer flag |

**Subtotal ~$65** · 3 of 6 purchased lines priced live

---

## 5. Station 2 — split + fan

**Ribbon geometry is now confirmed from the vendor spec, not deferred.** The
listing states conductor OD **1.40 mm**, 60 × 0.08 mm tinned copper (0.302 mm²,
genuine 22 AWG), PVC. Three conductors co-extruded tangent, so pitch = **1.40 mm**
and overall width = **4.20 mm**. `cell-design.md`'s 2.5 mm was the *connector*
cavity pitch borrowed by mistake.

🟢 **And the ribbon is designed to be pulled apart by hand** — that is what flat
JR/Futaba servo wire is *for*. The web is deliberately weak, which likely
collapses this station from a precision slitting die into a **printed splitting
wedge**. See [`docs/stations.md`](../docs/stations.md) §2.

| # | Item | Pick | Price | Qty | Notes |
|---|---|---|---|---|---|
| 5.1 | Splitting wedge | printed | — | 1 | **Replaces the two-blade die**, pending a 5-second hand test on the real ribbon |
| 5.2 | Spreader plate | printed, 1.40 → 8 mm over 25 mm | — | 1 | **7.5° splay** — no set in the insulation |
| 5.3 | Slitting blades + depth adjust + anvil | scalpel blades, M3 fine-pitch, ground flat | ⓘ ~$32 | 1 | **Only if the wedge route fails.** Held as the fallback, not the plan |

**Subtotal $0 if the wedge works, ~$32 if not** — plus, on the wedge route, one
fewer cylinder, valve and pair of flow controls (**−$8, −1 manifold station**).

**The test costs nothing:** when the ribbon arrives, zip 25 mm apart by hand and
watch whether the tear runs straight. That decides the station.

---

## 6. Station 3 — strip

| # | Item | Pick | Price | Qty | Notes |
|---|---|---|---|---|---|
| 6.1 | V-blade die, 3-position | HSS or repurposed stripper blades at 8 mm comb pitch | ⓘ ~$22 | 1 | **Unsourced.** One stroke scores all three — equal strip length by construction |
| 6.2 | Depth stop shims | [brass shim stock assortment](https://www.amazon.com/dp/B09V5LPSNB) `B09V5LPSNB` | ✅ **$9.92** | 1 | Wrong depth = nicked strands = the crimp fails a pull test two stations later |
| 6.3 | Slug waste chute | printed | — | 1 | Slugs drop away, not into the mechanism |

**Subtotal ~$32**

*(The pull-off is done by the arm retracting 4 mm — no dedicated actuator, but it
is why **R needs ≥50 N thrust** and therefore a leadscrew, not a belt.)*

---

## 7. Printed parts — and which filament each takes

Fifteen modelled. Generate with `freecadcmd cad/build_parts.py` — FCStd + STEP +
STL from the same `sim/layout.py` dimensions the simulation uses.

**The split rule:** *PETG where sustained load, creep or impact dominates. PLA+
where dimensional accuracy or fine features dominate.*

PLA creeps under constant room-temperature stress in a way PETG does not, so
anything permanently loaded is PETG. But PLA+ holds sharper features and better
dimensional accuracy, which matters more than toughness on the parts whose *fit*
is the functional requirement.

| Part | Filament | Vol cm³ | Qty | Why this material |
|---|---|---|---|---|
| `z_platform` | **PETG** | 268.9 | 1 | Carries the entire rotating assembly, permanently loaded |
| `station_mount` | **PETG** | 46.6 | 7 | Structural, permanently loaded |
| `spindle_shaft` | **PETG** | 94.1 | 1 | Bearing seats under constant load |
| `spool_hanger` | **PETG** | 81.0 | 1 | 150 mm upright under constant dancer tension — the classic PLA creep case |
| `guillotine_holder` | **PETG** | 75.1 | 1 | Repeated impact from the blade stroke |
| `drive_roller_block` | **PETG** | 67.0 | 1 | Constant spring preload at the nip |
| `radial_carriage` | **PETG** | 21.2 | 1 | Takes the ~50 N pull-off thrust |
| `wrist_mount` | **PETG** | 12.0 | 1 | Repeated flip loads and hard-stop impact |
| `spool` | PLA+ | 116.6 | 1 | Light, intermittent load; big flat print where PLA+ warps less |
| `camera_mount` | PLA+ | 29.5 | 1 | Light; slotted for adjustment |
| `guide_tube_mount` | PLA+ | 14.4 | 1 | Light; press-fit bore wants accuracy |
| `comb` | PLA+ | 9.3 | 1 | **1.8 mm channels are the functional fit** — sharper features beat toughness here, and load is guide-only |
| `dancer_arm` | PLA+ | 6.2 | 1 | Light |
| `spreader_plate` | PLA+ | 6.0 | 1 | Finest features in the build — 1.45 → 8 mm diverging slots |
| `measuring_wheel` | PLA+ | 5.3 | 1 | **Concentricity is everything** — PLA+ is the more dimensionally stable choice |

### Filament quantity

At ~60% effective density (walls plus ~40% infill):

| Material | Solid cm³ | With infill | Grams | Spools |
|---|---|---|---|---|
| **PETG** | 945.5 | 567 | **~720 g** | 0.72 |
| **PLA+** | 187.3 | 112 | **~139 g** | 0.14 |

**One 1 kg spool of each covers the whole build with margin** — and PETG is the
one you will actually consume, since `z_platform` and seven `station_mount`s are
62% of the total volume between them.

| # | Item | Pick | Price | Qty | Notes |
|---|---|---|---|---|---|
| 7.1 | PETG, 1 kg | [eSUN PETG 1.75 mm](https://www.amazon.com/dp/B07FXVGYKL) `B07FXVGYKL` | ✅ **$12.99** | 1 | Cheaper eSUN PETG line. Alt [`B0BN4Y1G2S`](https://www.amazon.com/dp/B0BN4Y1G2S) $21.99 |
| 7.2 | PLA+, 1 kg | [eSUN PLA+ 1.75 mm](https://www.amazon.com/dp/B07FQDKR28) `B07FQDKR28` | ✅ **$15.29** | 1 | The PLA+ you already run |

**Filament subtotal ~$28.**

Print notes and orientations in [`cad/README.md`](../cad/README.md). Still to
model: slug chute, body-clamp mount, cross-slide carrier.

## 7b. Arm camera

| # | Item | Pick | Price | Qty | Notes |
|---|---|---|---|---|---|
| 7b.1 | Camera | **ELP-USBFHD01M-L36**, 3.6 mm | **$0** | 1 | Kyle has spares. Same model as TendWright's fleet, so `cameras.py` / `camserve.py` work unchanged |
| 7b.2 | AprilTags | tag36h11, 25 mm, printed | — | 7 | Arm measures actual pose vs commanded at each stop |
| 7b.3 | Ring light | small LED ring or bar | ⓘ ~$12 | 1 | **Unsourced.** Tag detection needs consistent illumination more than brightness |
| 7b.4 | USB cable | 2 m, through the drag chain | ⓘ ~$8 | 1 | **Unsourced.** Must survive ±135° sweep plus Z stroke |

---

## 7c. Consumables — ribbon and reference cables

Carried over from `bom-v1.md`; these are Phase 1 items and belong here too.
**Re-verified live 2026-07-27.**

| # | Item | Pick | Price | Qty | Notes |
|---|---|---|---|---|---|
| 7c.1 | **Ribbon stock** | [YXQ 22 AWG servo cable, 50 ft](https://www.amazon.com/dp/B0CQ1V38RF) `B0CQ1V38RF` | ✅ **$9.30** | 2 | ⚠️ **Only 11 left in stock.** 22 AWG, 60 cores × 0.08 mm, black/red/white JR, 1.4 mm OD. One spool dev scrap, one for real cables |
| 7c.2 | Ribbon — alternate | [OliYin 50 ft 22 AWG 3-pin](https://www.amazon.com/dp/B071VN9DF1) `B071VN9DF1` | ✅ **$14.80** | — | **In Stock**, no quantity warning. Same 60-core spec. Use if 7c.1 sells out |
| 7c.3 | Ribbon — alternate 2 | [22 AWG servo extension, 50 ft](https://www.amazon.com/dp/B0F3D3SBBP) `B0F3D3SBBP` | ✅ **$14.99** | — | 20 left |
| 7c.4 | **Reference cables** | [waveshare 5264-3PIN, 6 pcs](https://www.amazon.com/dp/B0GVDFXF7Q) `B0GVDFXF7Q` | ✅ **$9.99** | 1 | **The factory-crimp yardstick.** True 5264 3-pin — the exact target connector. Measure its crimp height and pull force before cutting a single terminal |

**Consumables subtotal ~$28** (2× ribbon + reference cables).

**Buy the ribbon now.** It is the one Phase 1 line with a stock warning, it is
cheap, and **every station's tooling geometry depends on measuring its real
cross-section** — the ~1.45 mm conductor pitch that S2's blades depend on is
currently derived, not measured.

---

## 8. Decisions and flags

### The pneumatic wrist is dropped — $220 → $15

`cell-design.md` §5.2 specified a **pneumatic 180° rotary actuator**, reasoned as:
the wrist needs only two positions, so no servo. Sound on *control simplicity*.
Live pricing killed it — **Airtac HRQ10 $220.50, HRQ20 $252.54**, more than every
stepper on the machine combined. A NEMA 17 with a belt and two hard stops does the
same job for **$14.84** on a spare driver slot. Hard stops stay; the motor only
has to reach them.

### Deck is plywood or acrylic, not aluminium tooling plate

A 560 mm aluminium plate is $150+ and is the wrong thing to buy while station
positions are still placeholders. Ply or acrylic is re-drillable, and finding out
where the holes actually go is the whole point of Phase 1.

### Where the money is

Pneumatics are **~35%** of Phase 1, and the compressor alone is **14%**. If the
total needs to come down:

- Drop reed switches (−$33) — lose stroke confirmation, run dies open-loop
- Drop the spreader cylinder and hand-set the fan for early trials (−$8 + a valve)
- Integrated leadscrew motors (§3) — possibly ~$30 out *and* three axes simpler

---

## 9. Do NOT buy here

| Item | Why | Instead |
|---|---|---|
| Housings / terminal chain on Amazon | Packaging form decides whether an applicator can feed them, and Amazon listings are repackaged and unverifiable | Mouser / DigiKey — `bom-v1.md` |
| Machine applicator on Amazon | **Confirmed absent.** Two searches returned only hand ratcheting crimpers | eBay — `bom-v1.md` line 10 |
| Lazy-susan turntable | Rated for axial load, not moment. Tips under a cantilever | Paired 6810 spindle, line 3.2 |
| **AM-10 pneumatic crimper** | 🔴 Wrong machine class — a die-set plier that cannot feed a terminal chain | — |

---

## 10. Sourcing status

**~33 of 49 lines priced off a live page**, covering roughly 83% of the cost.

Still ⓘ **unsourced**, and why:

- **S3 tooling** (1 line) — the V-blade die geometry is not fixed.
- **S2 is now resolved on paper** — the vendor spec settled the ribbon geometry
  that was previously being deferred to "measure on arrival", and the
  hand-separable construction points at a printed wedge rather than a bought die.
  What remains is a materials question no datasheet answers: does the tear run
  straight for 25 mm. Answered by hand, free, the day the ribbon lands.
- **Consumables and hardware** (6 lines) — extrusion fasteners, wiring, dancer
  spring, drive rollers, guillotine blade, ring light, USB cable. Small, and most
  depend on the frame design.
- **Deck plate** — a local cut, not a catalogue item.

**Two estimates have now been checked against reality, and both were wrong in
different directions:** the rotary bearing 5× low, the motion controller 2× high.
That is why guesses get marked ⓘ rather than dressed up as prices.

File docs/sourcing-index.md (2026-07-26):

# Industrial sourcing index

Where to find parts, tools and CAD models for machine-building projects.
Organised by **what you are trying to buy**, because that is how you actually
use it — not alphabetically, and not as a link dump.

**Verification convention.** ✅ = hit live during a sourcing pass, with the date.
Everything else is general knowledge and should be treated as a starting point,
not a fact. Same rule as the BOM: an unverified link is a claim.

**Started** 2026-07-26 for CableCell, but deliberately written to be
project-agnostic — the next machine reuses it.

---

## 1. Crimp and applicator tooling

The hardest category to search, because the vocabulary is unusual and consumer
search engines return hand crimpers no matter what you ask for. Learn the words:
an **applicator** is the tooling that feeds a terminal chain and forms the crimp;
a **press** is the dumb machine that drives it; a **die set** is something else
entirely and will not feed a chain.

### Connector OEMs (the authoritative source)

| Source | Good for | Notes |
|---|---|---|
| [Molex Application Tooling](https://www.molex.com/en-us/products/application-tooling) ✅ 2026-07-26 | ATS specification PDFs per applicator, Mini-Mac and FineAdjust lines, custom tooling | The ATS docs are fully dimensioned drawings — the authoritative source for shut height and applicator geometry |
| [TE Application Tooling](https://www.te.com/en/products/application-tooling/applicators.html) ✅ 2026-07-26 | Applicator catalogue, AMP tooling | [Catalogue PDF](https://www.te.com/content/dam/te-com/documents/application-tooling/global/1-1773864-9_TE-Applicators_Catalog.pdf) |
| JST | Side-feed applicator manuals via distributor datasheets | Manuals often mirrored on DigiKey's media server |

### Applicator and press vendors

| Source | Good for | Notes |
|---|---|---|
| [Mecal by Starn](https://www.mecalbystarn.com/applicators-evs-side-feed-mini-applicator/) ✅ 2026-07-26 | EVS side-feed mini applicators | States the 135.8 mm ±0.02 shut-height standard explicitly |
| [ETCO](https://www.etco.com/application-equipment/) ✅ 2026-07-26 | Mighty-Mini applicators, presses, die sets | US-based; one-piece cast bodies, thick base plates |
| [Kingsing](https://www.kingsing.com/product/428.html) ✅ 2026-07-26 | Pneumatic side-feed and end-feed applicators | **119.7 mm shut height** — the clone standard, not the Western one |
| [crimpapplicator.com](https://www.crimpapplicator.com/product/123.html) ✅ 2026-07-26 | Left/right side-feed applicators | Also 119.7 mm |
| [Eastontech / ew-wirestripping](https://www.ew-wirestripping.com/Products/1/3/50/Terminal-crimping-machine.html) ✅ 2026-07-26 | 1.5T–5T terminal crimping presses | The class CableCell's press comes from |
| [Errebishop](https://errebishop.com/en/automatic-stripping-and-crimping/10328-15t15kn-taped-terminal-crimping-machine-for-mini-applicators-with-30mm-stroke.html) ✅ 2026-07-26 | Presses with real published specs | One of the few listings that publishes footprint/weight/power |
| [JCWelec](https://www.jcw-wirestripping.com/jcw-30cps-otp-type-pneumatic-horizontal-feed-terminal-crimp-applicator.html) ✅ 2026-07-26 | OTP-type pneumatic horizontal-feed applicators | |
| Sedeke — `info@sedeke.com` | **Custom applicator tooled to your terminal** | The route when no off-the-shelf applicator exists for your connector. Needs a press shank spec attached to any quote request |

### High end (reference and used-market targets)

Komax, Schleuniger, Artos, Metzner, Eubanks, Carpenter Mfg. Far beyond hobby
budget new, but worth knowing the names — they are what shows up on the used
market, and their documentation is the best free education available on how
these machines actually work.

### 🔴 Two traps this project already hit

1. **Die-set pliers are not applicator presses.** A machine marketed as
   "pneumatic, automatic, 14 die sets" crimps loose terminals hand-fed one at a
   time. It cannot feed a chain and cannot mount a standard applicator. Chain
   feed is usually the whole premise — check for it explicitly.
2. **"Standard" shut height means two different things.** 135.78 mm ±0.02
   (Molex/TE/Mecal, Western) vs **119.7 mm** (Chinese OTP clones). A 16 mm
   mismatch makes applicator and press incompatible. **Always ask which.**

---

## 2. Electronic components, connectors, terminals

| Source | Good for | Notes |
|---|---|---|
| [DigiKey](https://www.digikey.com) ✅ 2026-07-25 | Terminals, connectors, **packaging clarity** | Best in class for telling you whether a part ships as Cut Tape, Tape & Reel or loose-piece — which for crimp terminals decides whether an applicator can feed it |
| [Mouser](https://www.mouser.com) ✅ 2026-07-25 | Same catalogue, different stock | Also mirrors manufacturer datasheets and CAD |
| [Newark / Farnell](https://www.newark.com) ✅ 2026-07-25 | Third opinion on stock and price | |
| Arrow | Occasionally stocks what the others do not | Not verified |
| LCSC | Cheap passives and connectors, direct from Shenzhen | Not verified; long shipping |

**Packaging is a first-class spec for crimp terminals.** Loose-piece terminals
cannot be machine-fed. Confirm the carrier form before ordering, and re-confirm
on arrival that it is continuous carrier strip rather than embossed pocket tape.

---

## 3. Mechanical raw stock, fasteners, tooling

| Source | Good for | Notes |
|---|---|---|
| **[McMaster-Carr](https://www.mcmaster.com)** | Fasteners, tool steel, ground plate, springs, bearings, raw stock — and **a STEP file on essentially every part page** | The single most useful site in this document. No login for CAD, next-day delivery. "Source it and model it" is one click. Prices are all-in rather than cheapest |
| [Misumi](https://us.misumi-ec.com) | **Configurable** parts — shafts cut to length, extrusion, precision plates, linear components | CAD download with a free account. The configurator is the point: specify a shaft to 0.1 mm and it ships |
| [MSC Industrial](https://www.mscdirect.com) | Cutting tools, metrology, shop supply | |
| [Grainger](https://www.grainger.com) / [Zoro](https://www.zoro.com) | General MRO | Zoro is Grainger's cheaper consumer-facing channel — same catalogue, often lower price |
| [Fastenal](https://www.fastenal.com) | Fasteners in quantity, local branches | |

---

## 4. Motion — linear, rotary, transmission

| Source | Good for | Notes |
|---|---|---|
| [StepperOnline (OMC)](https://www.omc-stepperonline.com) | NEMA steppers, drivers, **ballscrew linear stages**, planetary gearboxes | Best price-per-quality in the hobby-to-light-industrial band |
| [VXB](https://vxb.com/products/100mm-cnc-linear-stage-sfu1605-sbr16) ✅ 2026-07-26 | Bearings, and **prebuilt SFU1605 linear stages** | Carries the exact Z-stage class CableCell needs |
| [OpenBuilds](https://openbuildspartstore.com) | V-slot extrusion, linear kits, plates | Good ecosystem docs; lighter duty than ballscrew stages |
| [ServoCity / Actobotics](https://www.servocity.com) | Hobby-grade shafts, hubs, gears, brackets that all fit each other | Excellent for prototyping mechanisms fast |
| Hiwin / THK / PBC Linear / igus | Industrial linear rails and bearings | igus publishes free CAD and sends samples generously |
| [Boca Bearings](https://www.bocabearings.com) | Specialty and thin-section bearings | Not verified |
| SDP/SI, Ruland, Lovejoy | Precision gears, couplings, timing belts | Not verified |

---

## 5. Pneumatics

| Source | Good for | Notes |
|---|---|---|
| [SMC](https://www.smcusa.com) / [Festo](https://www.festo.com) | Cylinders, valves, manifolds, rotary actuators — and **online configurators that emit STEP for the exact part number** | The configurator CAD is the reason to start here even if you buy elsewhere |
| [Clippard](https://www.clippard.com) | **Small-bore** cylinders and valves | The right scale for benchtop machines where SMC/Festo start too big |
| [AutomationDirect](https://www.automationdirect.com) | Valves, manifolds, sensors, fittings, PLCs | Free datasheets and CAD, US stock, genuinely good prices |
| Bimba | Cylinders | Not verified |

**Note for crimp work:** use a filter + regulator, deliberately *not* a full FRL.
A lubricator injects oil into the air, which is the last thing you want near
crimp tooling.

---

## 6. Vendor CAD and 3D models

The difference between a rough-in that takes a day and one that takes a week.

| Source | Format | Notes |
|---|---|---|
| **McMaster-Carr** | STEP | Per-part, no login. Best-in-class |
| [TraceParts](https://www.traceparts.com) | STEP, native | Huge aggregator — SMC, Festo, Hiwin, THK, igus. Free account |
| [3D ContentCentral](https://www.3dcontentcentral.com) | STEP, SolidWorks | Dassault-run, vendor-published |
| [GrabCAD](https://grabcad.com) | Mixed, **often STL** | User-uploaded — NEMA motors, MGN rails, generic hardware. Quality varies, verify dimensions. STL directly usable in MuJoCo |
| Molex / TE / JST product pages | STEP, IGES | Per-part connector and terminal models |
| SMC / Festo configurators | STEP | Exact ordered configuration |
| [Printables](https://www.printables.com) / Thingiverse | STL | Printed parts, spool holders, motor mounts |
| Onshape public documents | Native, exports STEP/STL | Searchable; everything on the free tier is public |

**MuJoCo eats STL/OBJ/MSH, not STEP.** Convert with FreeCAD (`Import` → `Mesh`,
scriptable headless) at a controlled deviation. Prefer sources that publish STL
directly when the part is only being visualised.

---

## 7. Surplus, used and auction

Where 5-figure industrial machines become 3-figure ones. Worth checking before
buying any press, applicator or metrology tool new.

| Source | Good for | Notes |
|---|---|---|
| [eBay](https://www.ebay.com) ✅ 2026-07-25 | Applicators, presses, tooling, metrology | The real market for clone applicators. Best Offer means price is negotiable. Watch shipping from CN — often $70–80 |
| Surplus Record | Used industrial machinery listings | Not verified |
| Machinio | Aggregates dealer inventory | Not verified |
| HGR Industrial Surplus | Bulk industrial surplus, photographed | Not verified |
| Bid on Equipment / IRS Auctions | Auction-format industrial | Not verified |
| [Surplus Center](https://www.surpluscenter.com) | Hydraulics, motors, odd mechanical | Not verified |

---

## 8. Direct import

| Source | Good for | Notes |
|---|---|---|
| AliExpress | Ballscrew stages, steppers, extrusion, OTP applicators | Same factories as the eBay listings, often cheaper, slower |
| Alibaba | Volume, and **talking to the actual manufacturer** | The route for custom tooling enquiries |
| [Robotdigg](https://www.robotdigg.com) | Niche automation and 3D-printer mechanical parts | Not verified |

**Import gotcha:** listing prices frequently include import fees but exclude a
substantial shipping charge that only appears at checkout. Budget landed cost,
never listed cost — this project's applicator estimate was off by 2× for exactly
this reason.

---

## 9. Metrology

| Source | Good for |
|---|---|
| McMaster, MSC, Grainger | Micrometers, calipers, gauge blocks, indicators |
| Amazon | Surprisingly competitive on iGaging/Mitutoyo-class instruments |

**Crimp height needs a point micrometer**, not calipers — flat anvils read a
B-crimp wrong. A general double-point mic (~$60) does the same job as a branded
"crimp height micrometer" (~$104–184).

---

## Workflow: finding tooling for an unusual part

The method that worked for CableCell, generalised:

1. **Get the OEM part number and its family** — not the marketplace description.
   Terminal chain 0008701039 in the Molex 5263 family, not "2.5 mm crimp pins."
2. **Check the OEM's own application tooling catalogue first.** They publish
   dimensioned specs even when they will not sell you a $250 tool.
3. **Search the specialist vendors** (§1) by *terminal family*, not by connector.
   Applicators are tooled to terminals.
4. **Check the used market** before accepting a new price.
5. **If nothing exists off the shelf, get a custom quote** — Sedeke-class vendors
   tool to a customer's terminal. Attach your press's shank spec.
6. **Verify the interface before buying**: shut height, feed direction, shank
   standard, and whether feed is mechanical (cam off the ram) or needs the
   vendor's own press. A tool that cannot mount is worth nothing.
7. **Confirm packaging** for anything consumable — carrier strip vs loose-piece
   decides whether the tooling can feed it at all.

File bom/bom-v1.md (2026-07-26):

# Cable Cell v1 — BOM (live-verified, all vendors)

**Verified:** Amazon 2026-07-24, eBay + press re-check 2026-07-25. Live passes in Kyle's browser session.
**Companion to:** `shopping-list-v1.md` (the reasoning) and `cell-design-v1.md` (the design of record).
**Status:** every Amazon and eBay line below was opened on its real product page and checked against the spec. Distributor lines (§1 rows 12–13) carry over from the earlier research and were *not* re-verified in this pass — flagged as such.

**Nothing here is ordered.** This is a buy list; clicking is Kyle's.

---

## 1. The BOM

| # | Item | Vendor | Pick | Unit | Ship | Qty | Spec check |
|---|---|---|---|---|---|---|---|
| 1 | Known-good reference cables | Amazon | [waveshare 5264-3PIN, 6 pcs](https://www.amazon.com/dp/B0GVDFXF7Q) `B0GVDFXF7Q` | $9.99 | $3.56 | 1 | ✅ True 5264 3-pin, the exact target connector. 3× 300 mm + 3× 900 mm. **The factory-crimp yardstick** — measure its crimp height and pull force before we cut a single terminal. |
| 2 | Ribbon stock | Amazon | [YXQ 22 AWG servo cable, 50 ft](https://www.amazon.com/dp/B0CQ1V38RF) `B0CQ1V38RF` | $9.30 | — | **2** | ✅ 22 AWG, 60 cores × 0.08 mm, black/red/white JR colors, 1.4 mm OD, flat 3-conductor. Matches the TendWright wiring doc. One spool dev scrap, one for real cables. |
| 3 | Crimp-height mic | Amazon | [iGaging 35-040-201, double point](https://www.amazon.com/dp/B00NDYTE4S) `B00NDYTE4S` | $58.50 | — | 1 | ✅ **Point anvils** — the whole reason for this line. 0–1", 0.00005". Flat calipers read the B-crimp wrong; only a point mic gets true crimp height (±0.05 mm class). Cheaper than the $104–184 "crimp height" branded units, same measurement. |
| 4 | Pull tester | Amazon | [KINGON hanging scale, 110 lb/50 kg](https://www.amazon.com/dp/B07B6SHFHV) `B07B6SHFHV` | $25.99 | — | 1 | ✅ 0.1 lb graduation, **peak/max hold** — essential, a pull test is a transient. Target ≈ 8 kgf pull-out on 22 AWG open-barrel. |
| 5 | Inspection scope | Amazon | [Jiusion 4K 50–1000× USB + metal stand](https://www.amazon.com/dp/B0CPVH11Z6) `B0CPVH11Z6` | $35.14 | — | 1 | ✅ Reads crimp wings and bell-mouth. Stand included — a handheld scope can't give repeatable crimp photos. Later doubles as the Q7 camera-check dev unit. |
| 6 | Terminal extractor | Amazon | [82-pc depinning kit](https://www.amazon.com/dp/B0922GF9W8) `B0922GF9W8` | $12.99 | — | 1 | ⚠️ Generic multi-profile, 4.3★. Covers 2.5 mm-class housings, not specifically tooled for 5264. Fine for insertion-jig scrap recovery. Precision fallback: [JRready ST5228](https://www.amazon.com/dp/B0B6FMZMH4) `B0B6FMZMH4` $29.99. |
| 7 | Spring assortment | Amazon | [Dianrui 300 pcs, 23 sizes, 304 SS](https://www.amazon.com/dp/B0BVTDP29W) `B0BVTDP29W` | $6.99 | — | 1 | ✅ Magazine follower + escapement return. 23 sizes gives room to tune follower force by trial. |
| 8 | Air prep | Amazon | [NANPU 1/4" NPT filter + regulator](https://www.amazon.com/dp/B07TPCGWPY) `B07TPCGWPY` | $15.99 | — | 1 | ⏸️ **DEFERRED to cell build — see §3.** ✅ Validated and correct when we need it: 5-micron brass, poly bowl, semi-auto drain, 0–150 psi, 20 SCFM, coupler kit + PTFE tape. **Filter+regulator, deliberately NOT a full FRL** — a lubricator injects oil into the air, the last thing we want near crimp tooling. |
| 9 | Compressor | Amazon | [California Air Tools 1P1060S, 1 gal](https://www.amazon.com/dp/B01LYHYHEA) `B01LYHYHEA` | $149.00 | — | 1 | ⏸️ **DEFERRED to cell build — see §3.** ✅ Validated: 56 dBA, oil-free, 1.20 CFM @ 90 psi, .6 HP, 29 lb. Nothing in de-risk needs air any more. |
| 10 | **Donor OTP applicator** | **eBay** | [OTP Horizontal Mold](https://www.ebay.com/itm/357379481619) `357379481619` — DYStore1, 100% | **$247.94** *or Best Offer* | $69.99 | 1 | ② **side feed confirmed in the listing** ("Horizontal Mold"). Single config, no variant guessing. ⚠️ ① XH2.54 series, ③ OTP shank, ④ cam-fed **all unconfirmed — needs a seller message first, see §5.** |
| 11 | Bench press | **eBay** | [1.5T Automatic Wire Crimping Machine](https://www.ebay.com/itm/157443920594) `157443920594` | $238.88 | free | 1 | ⚠️ **220 V, and deferred** — not a buy-now line. 30 mm stroke, 1.5 T, AWG18–30, takes standard mini-applicators. See §6 for the voltage/frequency picture and the machine-class trap. |
| 12 | Housings | Mouser / Newark | Molex **50-37-5033** — [Mouser](https://www.mouser.com/ProductDetail/Molex/50-37-5033?qs=AplfTeSvkkCfnVdKv8UuEg%3D%3D) · [Newark](https://www.newark.com/molex/50-37-5033/connector-rcpt-3pos-1row-2-5mm/dp/57H1785) | ~$0.15–0.25 | — | **100** | ⓘ *Not re-verified this pass.* Ships loose in a bag. 100 covers magazine-cartridge dev + insertion-jig scrap + real cables. |
| 13 | Terminal chain | DigiKey | Molex **0008701039** — [DigiKey](https://www.digikey.com/en/products/detail/molex/0008701039/765268) | ~$0.022 | — | **500–1000** (Cut Tape) | ⓘ *Not re-verified this pass.* ✅ Packaging resolved earlier: only Cut Tape (min 100) and Tape & Reel (min 12,000) exist — no loose-piece — so every form is carrier-strip and applicator-feedable. Verify continuous carrier, not embossed pocket tape, on arrival. |

### Totals

| Bucket | Cost |
|---|---|
| Amazon lines 1–7 (tools + consumables) | **~$168** |
| eBay applicator (line 10, landed) | **~$318** |
| Distributor consumables (lines 12–13) | ~$37 |
| **▶ BUY NOW (1–7, 10, 12–13)** | **~$523** |
| Air, deferred to cell build (lines 8–9, §3) | $165 |
| Press, deferred (line 11, §6) | $239 |
| **Everything, eventually** | **~$927** |

**What the buy-now bucket actually unblocks:** de-risk **B** (insertion jig — printed parts + hand-crimped pigtails into real housings), measuring the factory reference cables to establish the crimp-height and pull-force targets, and receiving + measuring the donor applicator to pick the punch/anvil route. De-risk **A** (machine crimping) additionally needs the press, so it waits.

---

## 2. Do NOT buy here

| Item | Why | Instead |
|---|---|---|
| ~~Raspberry Pi 5 8 GB~~ | ❌ **CUT — not needed.** Kyle has a stack of older NUCs plus cell1-class boxes. The design already made the supervisor architecture-independent, so this is a free swap. See §4. (Amazon was a trap anyway: cheapest kit $214.99 vs ~$80 board + $13 PSU direct.) | Nothing to buy. Supervisor $100–140 → **$0**. |
| Donor applicator, on Amazon | ❌ **Confirmed absent.** Two searches returned only hand ratcheting crimpers (SN-28B/SN-2549 class) — no machine applicators at any price. | eBay, line 10 |
| Housings / terminal chain, on Amazon | Packaging form matters and Amazon listings are repackaged and unverifiable | Mouser / DigiKey, lines 12–13 |
| **AM-10 pneumatic crimper** | 🔴 **Wrong machine class** — looks perfect at $159, isn't. See §6. | — |

---

## 3. Air is deferred entirely — nothing in de-risk needs it now

**Kyle 2026-07-25 dropped his pneumatic press find** ("if it's not what we need skip it"). That closes the question in §6 and has a clean knock-on effect: the press we'd actually buy (line 11) is an **electric** motor-and-cam 1.5T unit, so **de-risk A needs no compressed air at all.**

Air only comes back at cell-build time, for the ~10 pneumatic station actuators in the design (insertion pusher, guillotine, stripper clamp, wrist flip). Both air lines — the compressor (line 9) and the filter/regulator (line 8) — therefore move out of the buy-now bucket. That's **$165 deferred**, and it removes the only line that was in an unresolved hold.

Both picks stay validated and correct for when we get there; nothing needs re-researching, just re-pricing at purchase time.

### Still worth knowing: the 12 V inflator question (now moot for de-risk)

Kyle asked (2026-07-24) whether the car tire inflators he already owns are strong enough, and whether an adaptor could be made. Recorded because it will come back at cell-build time.

**The adaptor is trivial; the machine is the problem.** Plumbing an inflator to 1/4" NPT is a ~$10 fitting. Three real blockers:

1. **No tank.** The killer. Inflators are direct-drive with no receiver. A press cylinder draws a large slug of air in a fraction of a second, far above any continuous flow rate. With no tank, line pressure sags mid-stroke, so **crimp force varies shot to shot** — and crimp height is the one number the whole de-risk exists to control. We'd be measuring our air supply, not our tooling.
2. **Duty cycle.** Built to fill one tire then cool — typically 10–15 min before thermal cutoff. The cell has ~10 actuators cycling continuously.
3. **No pressure switch.** No way to hold a setpoint automatically.

**Where it genuinely works:** inflator **+ a separate 5-gal portable air tank (~$40) + the filter/regulator (line 8).** The tank does the buffering. For de-risk A — occasional manual strokes, not continuous cycling — that's legitimate, and it starts bench work for ~$40 instead of $149.

**Conclusion:** the compressor is a **permanent cell component** — the finished cell needs a tank, a pressure switch and a real duty cycle regardless. The inflator route was only ever a way to start de-risk A cheaply, and de-risk A no longer needs air. So this whole question is parked until cell build.

**When it comes back, to decide it:** check the inflator's label for max PSI (want ≥100 with headroom) and rated duty cycle.

---

## 4. Supervisor = spare NUC on Ubuntu (Pi cut)

**Decision, Kyle 2026-07-24.** The supervisor runs on existing hardware — Kyle has both cell1-class boxes and **a stack of older NUCs**. The NUC is the better pick and effectively ideal here.

**Why this is free rather than a compromise:** the split-brain design already puts *all* real-time work on a dedicated motion MCU (the Klipper/grblHAL pattern — supervisor thinks, MCU does microsecond step timing). The supervisor only runs the job queue, state machine, logging, web HMI, camera check and Hive reporting. None of that is Pi-specific, and x86 does it better: more CPU/RAM for vision, a real SSD instead of an SD card (SD corruption is a genuine long-run failure mode), native x86 dev, no ARM cross-compile friction.

**Why a NUC specifically:** it keeps every x86 advantage while erasing the only objection to a desktop — small enough to mount under the bench, quiet, ~10–20 W idle (nearer a Pi's 5 W than a tower's 30–60 W), plenty of USB, M.2/SATA SSD.

**The stack matters as much as the unit.** Spares turn a dead supervisor into a swap rather than a repair — image one, clone it, keep a cold spare. Real availability for a machine running unattended jobs. And if CableCell ever replicates, each cell gets a supervisor at zero hardware cost.

**Downstream changes:**

| Was | Now | Impact |
|---|---|---|
| Pi Camera 3 on CSI (~$35) | **USB camera** (~$25–35) | Small. Jiusion scope covers dev; a USB webcam covers the Q7 check. |
| Pi GPIO as a fallback for simple IO | **No GPIO on the supervisor** | None in practice — the design never used it. Does make the motion MCU strictly mandatory, but it already was. |
| ~$100–140 supervisor | **$0** | Bucket removed. |

**Remaining checks:** enough USB ports (camera + MCU + spare), an SSD you're happy to leave in service, 8 GB RAM ideal (4 GB workable).

**Unchanged:** the motion controller stays deferred (BTT/SKR-class or Duet) until Q1/Q2 settle the axis count.

---

## 5. Applicator — the one thing to settle before ordering line 10

**Price note:** the $80–160 estimate in `shopping-list-v1.md` was **stale**. Sorted by price+shipping ascending, the floor for a *complete* OTP applicator is ~$230–260 plus ~$70–80 shipping from China (import fees included in the listed price). Budget **~$320 landed**. The old cheap end was probably mold *inserts*, not complete units. Upper anchor: genuine precision units run [$1,546 side feed](https://www.ebay.com/itm/168452577707) to [$2,654 end feed](https://www.ebay.com/itm/168391214562) — so we're buying the $250 clone knowingly.

### Alternates to line 10

| Pick | Price | Ship | Note |
|---|---|---|---|
| [Multi-series OTP applicator](https://www.ebay.com/itm/314031005413) `314031005413` | $257.98 | $79.91 | ToolsMachinesGood (227), 99%. 2 available. Variant picker → choose **Horizontal Mold**. |
| [Same product, other seller](https://www.ebay.com/itm/146092754507) `146092754507` | $350.51 | $19.89 | ~$370 total. Fallback. |
| [Generic OTP applicator](https://www.ebay.com/itm/388629243167) `388629243167` | $231.50 | — | Cheapest complete unit. Feed type not stated. |

### 🔴 The trap: you cannot pick the terminal series at checkout

**None of these listings let you select the terminal series.** On the multi-series listing the dropdown that *looks* like it picks the series is labelled "Color" (a common CN-listing quirk) but actually selects **feed geometry** — Single / Horizontal / Straight Mold. The XH2.54 / 1.25 / SM / 3.96 / 5557 list in the title is the seller's tooling *range*, not a menu.

Checklist status:

- ② **side feed** — ✅ selectable, choose "Horizontal Mold"
- ① **XH2.54 variant** — ⚠️ confirm with seller
- ③ **OTP-standard body/shank** — ⚠️ confirm with seller
- ④ **mechanical cam-fed, not proprietary-press** — ⚠️ confirm with seller

**Message for Kyle to send** (no seller has been contacted):

> Which terminal series is this applicator tooled for — can you supply it tooled for JST XH 2.5 mm open-barrel terminals? Is the body/shank the OTP standard mount so it fits a generic bench press, and is the chain feed mechanical (cam driven off the ram) rather than requiring your own press?

Ask DYStore1 (line 10) first — side feed is already confirmed there, it's Best Offer so price can move, and it's the cheapest meeting a hard requirement outright.

**Not fatal either way:** this unit is bought as a **donor chassis and mechanism reference** — frame, ram geometry, feed cam, drag brake. If the punch/anvil suits 5263 geometry that's route 1 (transplant, $0). If not we measure it and move to route 2 (buy inserts) or route 3 (machine our own), which was always the plan.

---
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

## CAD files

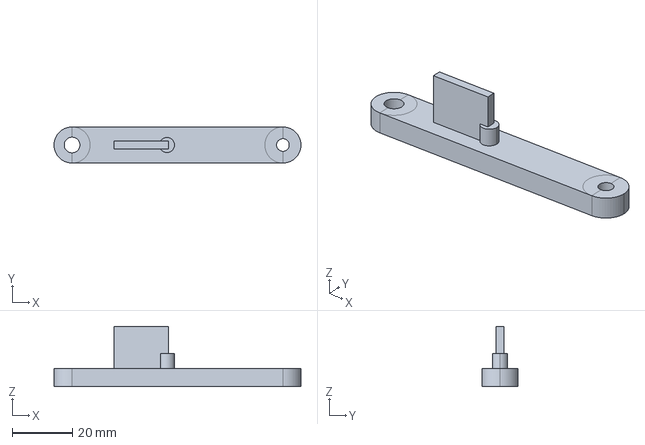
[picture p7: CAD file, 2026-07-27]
cad/parts/dancer_arm.step
82.0 x 12.0 x 20.0 mm

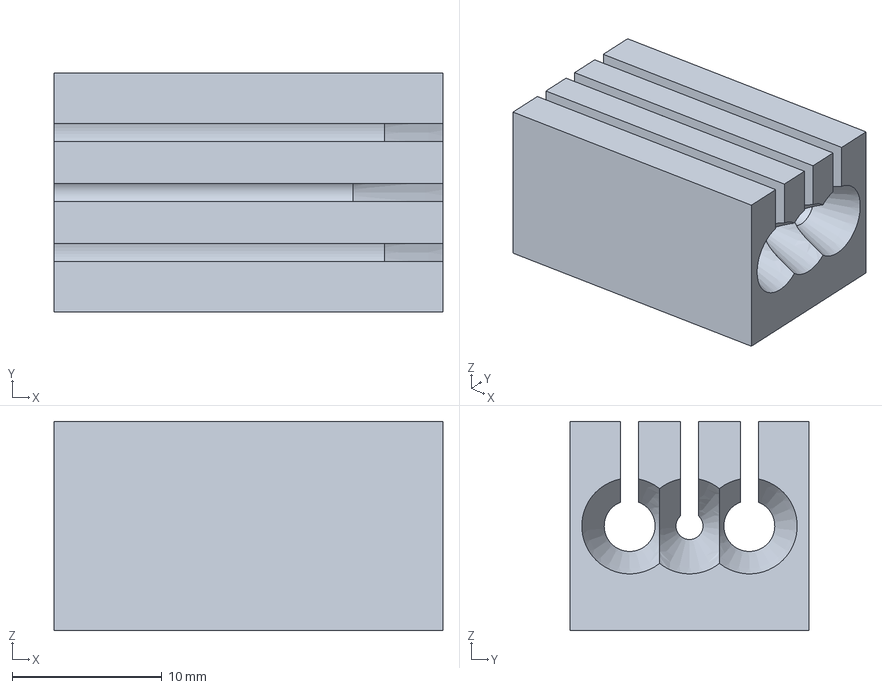
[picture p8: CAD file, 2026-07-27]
cad/parts/comb.step
26.0 x 16.0 x 14.0 mm

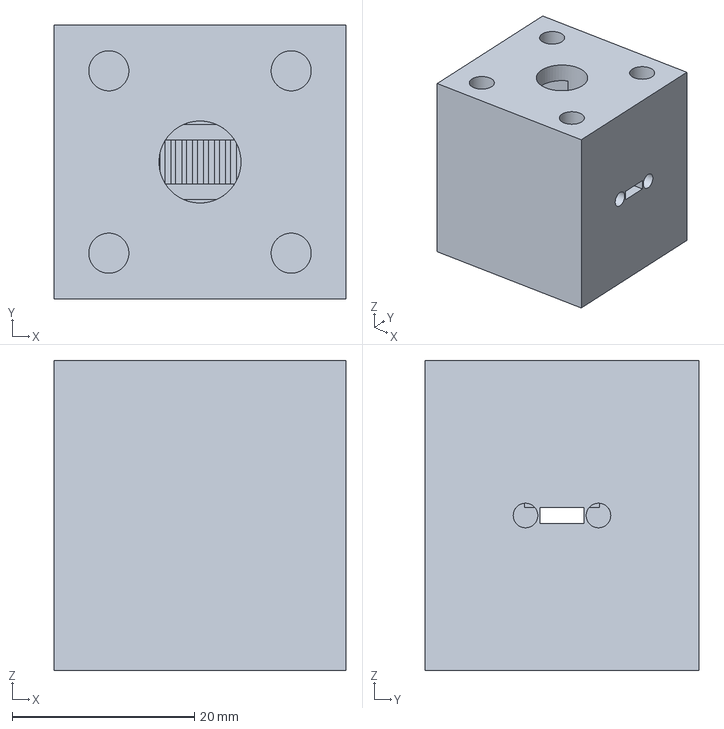
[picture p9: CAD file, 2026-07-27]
cad/parts/body_clamp.step
32.0 x 30.0 x 34.0 mm

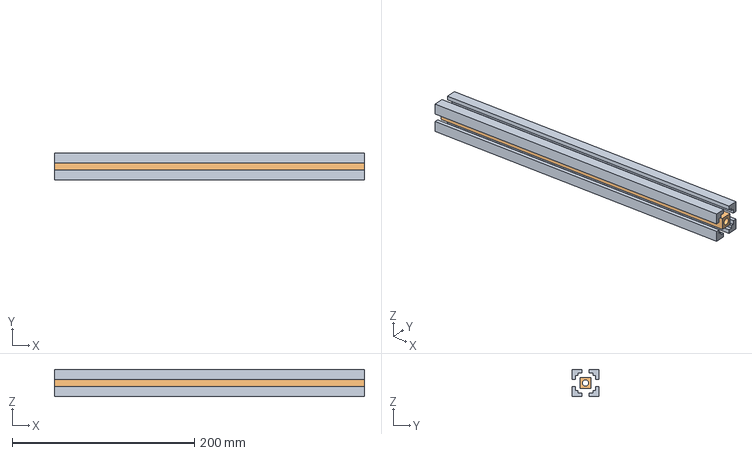
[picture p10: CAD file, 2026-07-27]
cad/parts/ext3030_340.step
340.0 x 30.0 x 30.0 mm

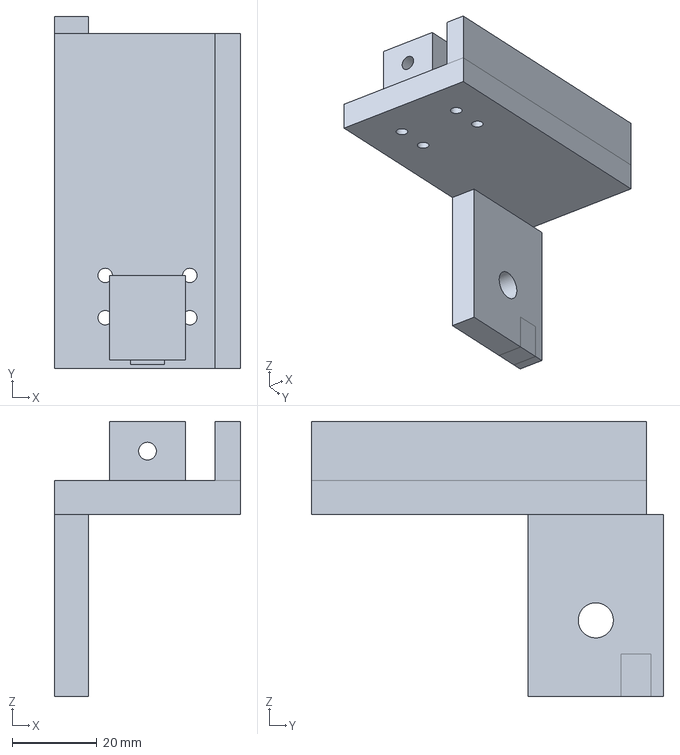
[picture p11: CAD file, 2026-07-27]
cad/parts/cross_slide_carrier.step
44.0 x 83.2 x 65.0 mm

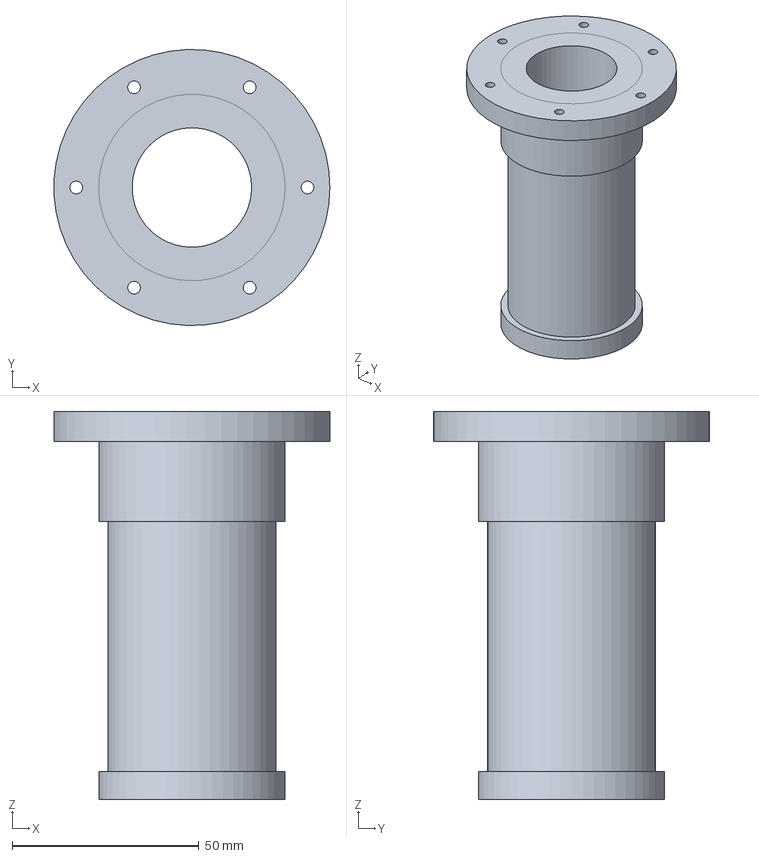
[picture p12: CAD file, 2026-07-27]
cad/parts/spindle_shaft.step
73.9 x 74.0 x 104.0 mm

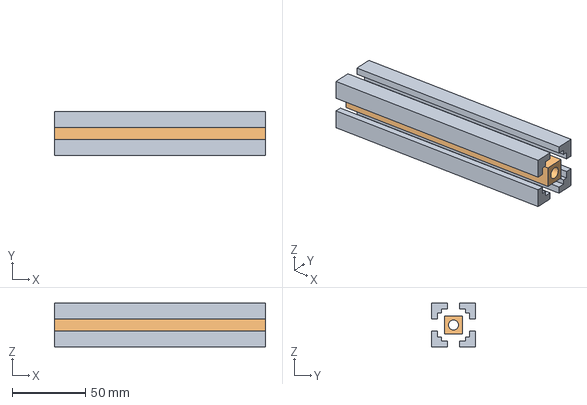
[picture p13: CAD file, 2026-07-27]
cad/parts/ext3030_144.step
144.0 x 30.0 x 30.0 mm

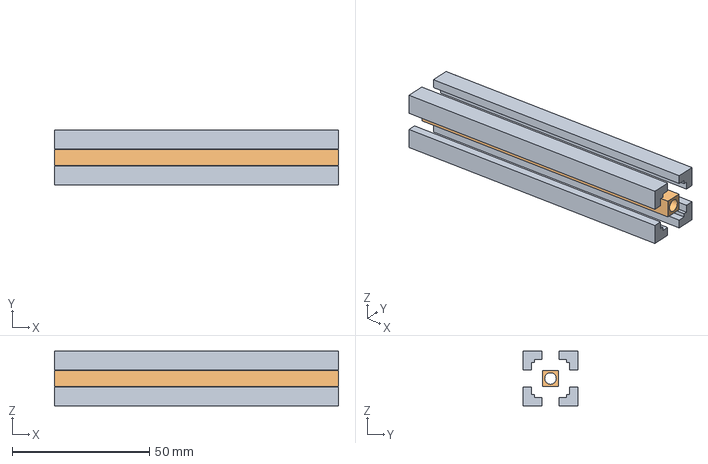
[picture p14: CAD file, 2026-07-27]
cad/parts/ext2020_104.step
103.5 x 20.0 x 20.0 mm

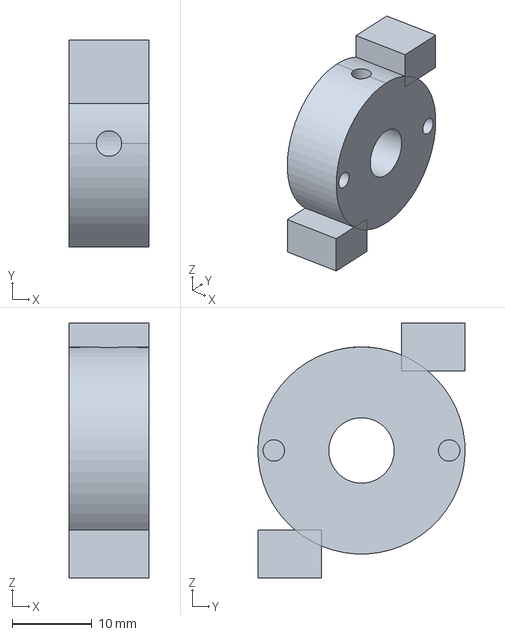
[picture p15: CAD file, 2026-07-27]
cad/parts/wrist_mount.step
10.0 x 26.0 x 32.0 mm

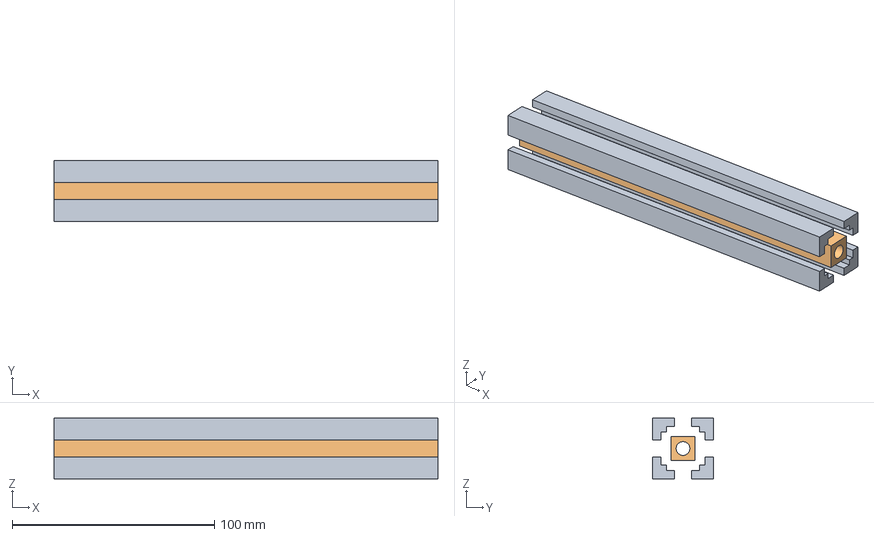
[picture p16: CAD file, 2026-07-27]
cad/parts/ext3030_190.step
190.0 x 30.0 x 30.0 mm

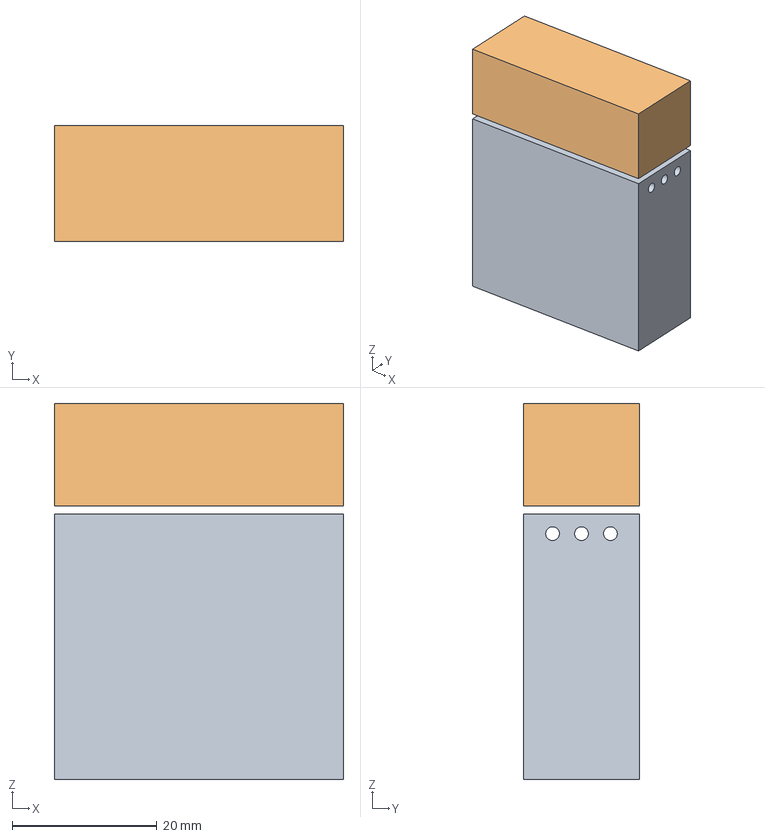
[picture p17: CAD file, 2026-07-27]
cad/parts/strip_die.step
40.0 x 16.0 x 52.0 mm

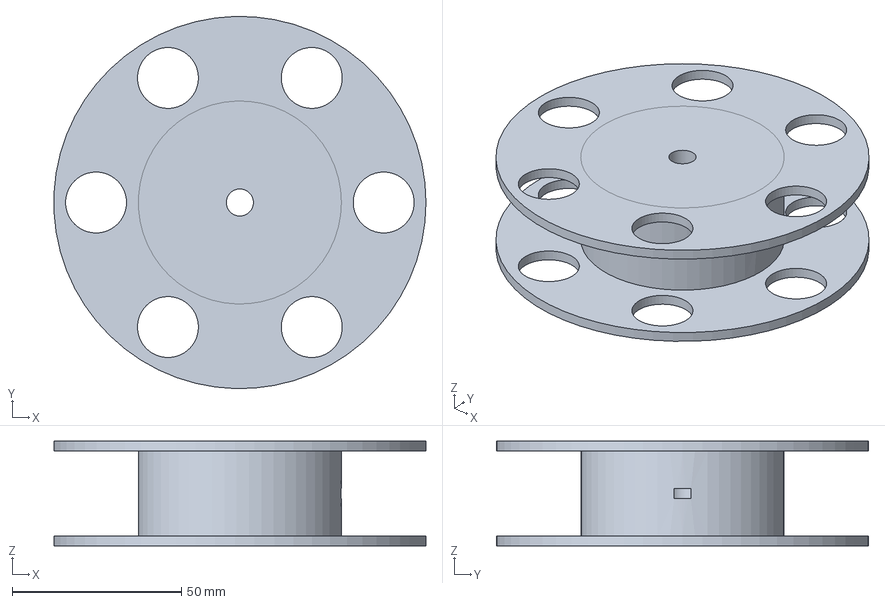
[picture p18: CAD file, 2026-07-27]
cad/parts/spool.step
109.9 x 110.0 x 31.0 mm

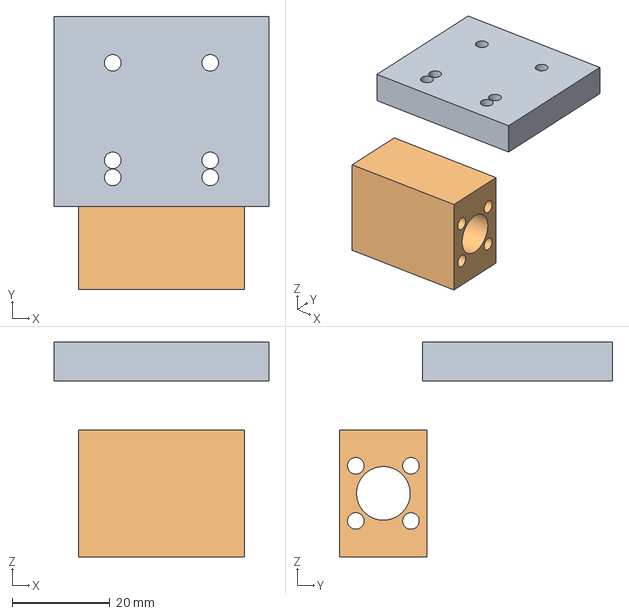
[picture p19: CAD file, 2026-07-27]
cad/parts/radial_carriage.step
44.0 x 56.0 x 44.0 mm

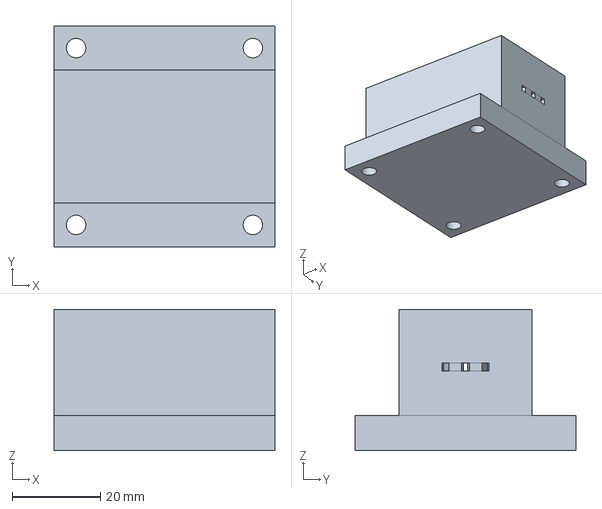
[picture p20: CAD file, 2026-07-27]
cad/parts/splitting_wedge.step
50.0 x 50.0 x 32.0 mm

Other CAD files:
cad/parts/station_mount.step
cad/parts/camera_mount.step
cad/parts/rotor_plate.step
cad/parts/drop_chute.step
cad/parts/body_clamp.FCStd
cad/parts/body_clamp.stl
cad/parts/camera_mount.FCStd
cad/parts/camera_mount.stl
cad/parts/comb.FCStd
cad/parts/comb.stl
cad/parts/cross_slide_carrier.FCStd
cad/parts/cross_slide_carrier.stl
cad/parts/dancer_arm.FCStd
cad/parts/dancer_arm.stl
cad/parts/drive_roller_block.FCStd
cad/parts/drive_roller_block.step
cad/parts/drive_roller_block.stl
cad/parts/drop_chute.FCStd
cad/parts/drop_chute.stl
cad/parts/ext2020_104.FCStd
cad/parts/ext2020_104.stl
cad/parts/ext3030_144.FCStd
cad/parts/ext3030_144.stl
cad/parts/ext3030_190.FCStd
cad/parts/ext3030_190.stl
cad/parts/ext3030_340.FCStd
cad/parts/ext3030_340.stl
cad/parts/feed_head.FCStd
cad/parts/feed_head.step
cad/parts/feed_head.stl
cad/parts/measuring_wheel.FCStd
cad/parts/measuring_wheel.step
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

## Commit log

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2026-07-26 Layout rough-in: fit check kills the 300mm bolt circle
    Adds sim/layout.py as the single source of every dimension, and
    sim/studies/fit_check.py, which answers whether the rotary layout closes
    using arithmetic alone — before any scene is built.
    Two results:
    R0 = 200mm, not 150mm. The ~300mm bolt circle carried in cell-design.md
    since the architecture was picked does NOT close. Seven angular stops (six
    stations plus a separate reject position) share a 270 degree arc, and the
    press is 210mm wide against a normal station's ~80mm. At R0=150 the layout
    needs 274.4 degrees of 270 — short by 4.4. Minimum viable ~175mm; working
    value 200mm leaves 68 degrees spare. The original figure was writte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
2026-07-26 Rough-in: MuJoCo scene generated from layout.py, plus rendered views
    sim/build_scene.py emits the MJCF entirely from layout.py — every geom traces
    to a named dimension. sim/run_cell.py opens it in the viewer and regenerates
    first, so editing a dimension and re-running is the whole iteration loop.
    Fixes a unit bug caught while getting the first render out: the crimp_point
    site was placed in millimetres rather than metres, putting it 141 m from the
    origin. That inflated the model extent to 141 m, so the auto-framed camera sat
    212 m away and the cell rendered as an invisible speck. Extent is now 0.815 m.
    Also switched the rendered views from hand-authored <camera xyaxes> to
    programmatic azi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
2026-07-26 Deflection budget is about variance, not strength
    Kyle: the cables are small and light, worst case 3-4 ft, nowhere near a pound.
    Correct and decisive. A 1.2m length of the ribbon is ~15-20g against a ~2kg
    rotating assembly — payload is ~1% of moving mass and irrelevant to any load
    calculation.
    So the budget was never set by payload. It is set by arriving inside the
    insertion funnel's capture window (~1.5 mrad across the whole stack at 200mm
    reach). That makes it a precision problem, and precision cares about VARIANCE:
    with a constant ~20g payload a cantilever's sag is repeatable, and repeatable
    sag folds into the per-station Z table as calibration rather than error. What
    defeats a cantile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
2026-07-27 Spool, hanger, arm camera and three-post Z stage in the rough-in
    Ribbon and spool now in layout.py. The wire ships as a loose roll, not on a
    rigid spool, so the spool is ours to design: printed, 110mm OD, 31mm wide,
    8mm bore matching the Z-stage rod stock. spool_capacity_m() computes 17.9m
    against a 15.24m stock roll — takes a whole roll with margin.
    Ribbon pitch corrected to ~1.45mm from the ~2.5mm in cell-design.md, which
    was the connector cavity pitch borrowed by mistake.
    Arm camera added, riding the RADIAL carriage — deliberately not the wrist,
    which flips 180 degrees. Reuses TendWright's fleet hardware and its
    cameras.py/camserve.py pattern (identity by USB port path, because devi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
2026-07-27 CAD pipeline: printable parts as real B-rep solids
    cad/build_parts.py generates five parts under FreeCAD's headless Python,
    exporting FCStd + STEP + STL for each. Dimensions come from sim/layout.py —
    the same single source the MuJoCo scene reads — so the printable parts and the
    simulation cannot drift.
    spool 110 x 110 x 31 116.6 cm3
    spool_hanger 70 x 44 x 150 81.0 cm3
    dancer_arm 82 x 12 x 20 6.2 cm3
    comb 26 x 32 x 12 9.3 cm3
    guide_tube_mount 34 x 24 x 29 14.4 cm3
    Three FreeCAD traps cost real time and are recorded in cad/README.md so they
    are not re-found:
    - Shape.translate() mutates in place and returns None. Chai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
    [comb.FCStd, comb.step, comb.stl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]
2026-07-27 S1-S3 station design, and the arm spec it produces
    docs/stations.md designs the three ribbon-prep stations in enough detail to
    derive what the arm must actually do — which is the point of designing them
    before building them.
    Two numbers chosen rather than inherited:
    Measuring wheel is 31.83mm diameter = EXACTLY 100.00mm circumference, so with
    a 600 P/R quadrature encoder length in mm is counts * 100 / 2400, 0.0417mm per
    count. No calibration constant to get wrong in the arithmetic. Deliberately no
    rubber tyre — a compliant surface changes effective circumference and its
    compression varies with preload, which is the exact error the wheel exists to
    avoid. The 100.00mm is still nominal an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
    [comb.FCStd, comb.step, dancer_arm.FCStd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]
2026-07-27 Arm structural parts, and a geometry clash the model caught
    Four printed parts for the arm — z_platform, radial_carriage, wrist_mount,
    camera_mount — bringing the CAD set to eleven. Designed against industry-
    standard footprints (LM8UU, MGN12H/MGN9C bolt patterns, NEMA 17, T8 nut
    flange) now recorded in layout.py, so they are safe to model before the
    specific parts are ordered.
    CLASH CAUGHT: the Z guide posts were on a 46mm circle, but a 90mm-bore slew
    ring runs ~120mm OD — anything inside r=60 fouls the bearing. The posts were
    inside the bearing they were meant to surround. Moved to a 78mm circle, which
    gives 14mm of radial clearance. This is exactly the class of error the model
    exis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
    [camera_mount.FCStd, camera_mount.step, camera_mount.stl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]
2026-07-27 BOM: printed parts and arm camera folded in
    Eleven printed parts now modelled and listed with real volumes — ~600 cm3,
    roughly 750g of filament, $20-25. Arm camera section added: the ELP board
    itself is $0 (Kyle has spares, and it is the same model as TendWright's fleet
    so cameras.py/camserve.py work unchanged), plus tags, a ring light and a
    drag-chain-rated USB cable.
    Measuring wheel and encoder lines sharpened with the chosen numbers: 31.83mm
    diameter for exactly 100.00mm circumference, 600 P/R quadrature, 0.0417mm per
    count, and an explicit no-rubber-tyre note since a compliant surface changes
    effective circumference — the exact error the wheel exists to avoid.
    Phase 1 total ~$1,125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
2026-07-27 S1 feed and cut parts, plus a generic station mount
    Fourteen printed parts now. Three new:
    drive_roller_block — the feed nip. Pays ribbon out and pulls it back, and
    deliberately does NOT measure: a driven roller slips against the ribbon under
    any tension change, and cable length is the machine's headline spec. The idler
    rides in a slot with a spring behind it, so preload is set by spring choice
    rather than by how hard someone did a screw up.
    guillotine_holder — takes a standard replaceable chisel blade against a close
    anvil. The 0.9mm blade guideway sitting tight to the ribbon passage is what
    makes it shear rather than crush, and a crushed end will not enter the comb
    channels. That fai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
    [camera_mount.FCStd, camera_mount.step, comb.FCStd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]
2026-07-27 Arm camera framing study, and three bugs it surfaced
    sim/studies/camera_check.py drives the arm to every stop and reports, per
    station: is the tag in frame, range, off-axis angle, and obliquity. Obliquity
    is the one people forget — AprilTag pose degrades sharply past ~60 degrees
    off-normal because projected area collapses and corner localisation gets noisy.
    A tag you can see is not necessarily a tag you can measure.
    Writing the study immediately found three real errors:
    1. THE COMB WAS 28mm ABOVE WHERE EVERY STATION EXPECTS THE RIBBON.
    COMB_ABOVE_ROTOR was set to min(STATION_Z), which silently ignored the
    carriage and rotor stack underneath it. STATION_Z is measured from the DECK;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
2026-07-27 Derive station angles from real widths instead of an even spread
    assign_station_angles() walks the seven stops in cycle order, giving each its
    own angular half-width at R0 and sharing the leftover arc equally as gaps. The
    press is 210mm wide against a normal station's 80mm — 31.7 degrees of half-width
    against 11.5 — so an even spread was always wrong: it either crowds the press or
    wastes arc.
    S1_FEED 0.0 S4_CRIMP 118.6 (half-width 31.7)
    S2_SLIT 32.8 S5_INSERT 171.5
    S3_STRIP 65.6 S6_DROP 204.4
    S6_REJECT 237.2
    Last stop at 237.2 of 270 degrees, 32.8 spare. Applied at import so the scene
    builder, the studies and the CAD all see the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
2026-07-27 Cycle animation: drive the arm through all seven stops
    sim/run_cycle.py runs the real motion sequence minus the tooling — lift to a
    rotation-safe height, index to the next station, descend to that station's
    engagement Z, extend, dwell, retract, lift, repeat. Cross-slide steps through
    conductors 1/2/3 at the stations that need it, and the wrist flips 180 once per
    cable after the cut.
    That lift-rotate-descend pattern is the base-mounted Z axis earning its keep:
    without it, rotation clearance has to come from radial retraction alone, which
    forces every station's tooling outside the bolt circle.
    Three modes:
    uv run python -m sim.run_cycle interactive viewer, loops
    uv run pyt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
2026-07-27 Add pillow; real slew-ring pricing kills a second post-circle clash
    Adds pillow==12.3.0 per Kyle authorization 2026-07-26. Lockfile diff verified
    against the disclosure: exactly one package, zero transitives, as stated.
    Rationale, alternatives and cost recorded in docs/dependencies.md, which now
    documents every dep and every machine-level tool.
    sim/imaging.py replaces the hand-rolled PNG writer and adds two things it could
    not do: text labels burned into frames, and animated GIF output. The contact
    sheet is now self-explaining rather than needing its reading order described in
    prose alongside the image — which was the actual argument for the dependency.
    uv run python -m sim.run_cycle -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
    [camera_mount.FCStd, camera_mount.step, comb.FCStd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]
2026-07-27 Paired-6810 spindle replaces the slew ring; centre section shrinks 33%
    A slew ring resists moment in one plane, buying its lever arm from its own
    diameter — which is why they get big and expensive fast. Two deep-groove
    bearings spaced vertically resist the same moment as a COUPLE, and the lever arm
    is the spacing, which costs nothing because the platform is already thick.
    The arm applies ~12 N*m. At 50mm spacing that is 240 N radial per bearing
    against a 6810's ~6200 N static rating — 26x margin.
    Knock-on: 65mm bearing OD instead of a 160mm ring lets the Z guide posts come
    back in.
    post circle 98.0 -> 56.5 mm
    z_platform 248 -> 165 mm
    bearing cost $199 -> ~$20-70 for the p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
    [camera_mount.FCStd, camera_mount.step, comb.FCStd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]
2026-07-27 BOM: real spindle-bearing pricing, and an honest sourcing status
    Applies the source-bom skill to the Phase 1 BOM. The bearing line is now priced
    off a real page (VXB 6810-2RS, $24.99-34.99 each, verified 2026-07-26) and the
    lazy-susan suggestion is recorded as withdrawn with the reason: rated for axial
    load on a table, not moment, and its play would have invalidated the stiffness
    test that justifies building Phase 1 at full R0.
    Adds section 10, stating plainly what is and is not sourced:
    5 lines priced off a real page
    2 lines class-confirmed only
    ~30 lines UNSOURCED
    The total now carries a warning rather than standing alone, because the one ⓘ
    figure that has since been checked was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
2026-07-27 Live sourcing pass: ~27 of 43 BOM lines now priced off real pages
    Ran the amazon-shopping-pass in Kyle's logged-in Chrome. Coverage goes from
    about 20% of cost sourced to roughly 80%.
    Technique worth keeping: instead of navigating per item, a same-origin fetch from
    an already-loaded Amazon page parses search results in bulk — four searches per
    tool call, no tab storm in Kyle's browser. Added to how this gets done.
    Biggest correction: the motion controller was estimated at ~$110 and is $53.99.
    That is 2x HIGH, in the opposite direction to the slew ring which was 5x LOW.
    Two estimates checked against reality this week, both wrong, opposite ways. That
    is the whole argument for marking guess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
2026-07-27 Filament mapping, ribbon consumables, and an imperial deck cut sheet
    FILAMENT. Every printed part now mapped to a material with a stated reason.
    Rule: PETG where sustained load, creep or impact dominates; PLA+ where
    dimensional accuracy or fine features dominate. PLA creeps under constant
    room-temperature stress in a way PETG does not, so anything permanently loaded
    is PETG.
    That reverses an earlier note which put the comb in PETG for toughness. Wrong
    call: its 1.8mm channels are the functional fit, sharper features beat toughness
    there, and the load is guide-only. Same reasoning moves measuring_wheel and
    spreader_plate to PLA+.
    Quantities at ~60% effective density: 720g PETG, 139g PLA+. O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
2026-07-27 Ribbon spec read off the listing; S2 likely collapses to a printed wedge
    Kyle: "you are still deferring on some stuff because of the wire, you should
    have the data for that from the product page specs." Correct — the listing had
    it and I had not read it.
    CONFIRMED, no longer derived or deferred: conductor OD 1.40mm (the listing says
    "Outer Diameter of Cable: 1.4mm"), 60 x 0.08mm tinned copper = 0.302mm2 which
    checks out as genuine 22 AWG, PVC insulation, 250g per 50ft. Three conductors
    co-extruded tangent, so pitch = OD = 1.40mm and overall width = 4.20mm. Six
    layout.py values move from ESTIMATED/derived to COMMITTED.
    The bigger find is behavioural, not dimensional: FLAT JR/FUTABA SERVO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
    [camera_mount.FCStd, camera_mount.step, comb.FCStd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]
2026-07-27 Death to greybox: real printed geometry at every station we have designed
    Swaps the placeholder station blocks for the 16 CAD parts that were already
    modelled and sitting unused in cad/parts/. S1 and S2 are now real assemblies;
    the arm carries its real platform, spindle, carriage, wrist and camera mount.
    The press stays a box, deliberately and with a comment saying why (Kyle
    2026-07-27, "sure press is still a box"): we have footprint, height and weight
    and nothing else, so drawing a detailed press would be inventing detail.
    Greybox where we are ignorant is honest. S3, S5 and both S6 chutes are grey for
    the same reason and each says which.
    New: S2's splitting wedge. Kyle 2026-07-27 committe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
    [camera_mount.FCStd, camera_mount.step, comb.FCStd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]
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2026-07-27 One derived engagement plane: Z stroke 100 -> 50 mm
    Kyle asked for STATION_Z to be derived and for travel to be minimal. Those pull
    against each other: deriving a height PER STATION from that station's tallest
    part gives every stop a different height, and the spread between stops becomes
    travel the Z stage is then obliged to have.
    So it is derived once, from the tallest part anywhere on the dial:
    STATION_TOOLING_HEIGHT = DECK_THICKNESS + STATION_MOUNT_T
    + max(STATION_PART_PASSAGE)
    Every station meets the ribbon on that plane; each shorter part is packed up to
    it by a printed standoff. The guillotine sets the plane and its standoff comes
    out at exactly 0.0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
    [camera_mount.FCStd, camera_mount.step, comb.FCStd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]
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2026-07-27 Feed module comes off the dial: S1 is one part, path is clear
    Kyle 2026-07-27: "we should do the simplest thing possible, the smallest thing
    possible ... whatever will make the feed module do its purpose to the overall
    machine best."
    Applying that changes the answer from either option I had put up. The 196 mm of
    radial run S1 needed was self-inflicted: I had assumed the feed train must sit
    in a line on the deck because that is how it was first drawn. But nothing
    upstream of the cut has any relationship to the dial - the ribbon reaches the
    machine through PTFE tube, and tube routes anywhere.
    So:
    - feed_head replaces guide_tube_mount + guillotine_holder. Two parts bolted
    in line doing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
    [camera_mount.FCStd, camera_mount.step, comb.FCStd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]
2026-07-27 The three undone parts: cross-slide carrier, body clamp, strip die
    cross_slide_carrier - the S axis. 20 mm stroke in 8 mm steps, which selects
    conductor 1, 2 or 3 at comb pitch; the stroke is exactly 2x COMB_PITCH rather
    than a round number for that reason. Takes almost no load, because the 50 N
    pull-off runs along R not S - sizing it for the pull-off would have been the
    obvious mistake. Replaces the last primitive box on the arm.
    body_clamp - the part that must not slip. S3 pulls insulation off by RETRACTING
    THE ARM 4 mm, so there is no pull-off actuator and this clamp takes the whole
    50 N. If the ribbon creeps here, strip length is wrong AND measured cable length
    is wrong, because the rib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
    [body_clamp.FCStd, body_clamp.step, body_clamp.stl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]
2026-07-27 The ribbon, as simulated material - and two things it exposed
    Every machine operation is now a constraint being switched off, which is not a
    simulation shortcut but the most honest description of the tooling: the
    guillotine's whole job is to stop the workpiece being attached to the stock, and
    the wedge's whole job is to stop the conductors being attached to each other.
    A cut is a topology change and MuJoCo cannot delete a joint at runtime, so the
    ribbon is built pre-severed and held together by equalities. That constraint
    forced the right model - three conductors joined by two webs, which is what flat
    servo wire physically IS. 49 bodies, 22 named equalities, all addressable.
    sim/ribbon.py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
2026-07-27 The arm goes straight through the Z posts, and nothing here caught it
    Kyle found it by looking at the viewer: "how can the arm just travel trough
    them?" It cannot.
    post circle radius 56.5 mm
    arm beam spans radius 44.5 .. 230.0 mm -> crosses it
    post top 266.0 mm above bench
    arm beam height 230.0 mm -> 36 mm below
    The arm would destroy all three guide posts and the leadscrew on the first
    rotation.
    WHY NOTHING CAUGHT IT. Every geom in the generated scene carries contype="0"
    conaffinity="0" - contacts are disabled throughout for render speed, so bodies
    pass through each other silently and a played cycle looks correct no matter w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
    [body_clamp.FCStd, body_clamp.step, camera_mount.FCStd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]
2026-07-27 Z stage drops below the deck: the arm stops going through the posts
    before posts topped out 266 mm, arm swept at 230 -> HIT, 46 mm deep
    after posts top out 184 mm, arm sweeps at 230 -> clear by 36 mm
    The platform was mounted ON the deck. That forced the guide posts to stand ~80 mm
    proud of it, because they have to keep guiding the platform's bearings at the top
    of travel - straight through the arm's sweep. The deck already had a 7" centre
    clearance hole cut for the platform to pass THROUGH; the scene simply was not
    using it.
    Second benefit, and why this is a better design and not just a fix: it gives the
    spindle room to be tall, so the two 6810s move from 50 to 75 mm apart.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
    [body_clamp.FCStd, body_clamp.step, camera_mount.FCStd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]
2026-07-27 Let MuJoCo find the interference: 34 pairs, and the arm stack is the cause
    Kyle, on the viewer: "the arm still collides with the stations then there are a
    lot of 'boxes' on the arm that seem to just pass through the arm structure ...
    this still seems like a fantasy render." Correct on every count.
    Every part's own geometry is real - built from layout.py, the same numbers that
    produce the printable STL. Where the parts sit RELATIVE TO EACH OTHER on the arm
    was not: carriage, cross-slide, wrist, camera and clamp were placed with
    hand-typed offsets like pos="-0.030 0 -0.014", none ever checked.
    My deeper mistake: the display scene disables contacts everywhere so it renders
    fast, and I answere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
2026-07-27 The arm was never added up: derive the stack, assert it, 115 -> 4
    MuJoCo with contacts on reported 115 interfering pairs. Reading them rather
    than counting them, they were two problems and a pile of consequences.
    THE STATION TAG LEDGE. station_mount carried a 30 mm wall on its inboard
    face so the camera could read the AprilTag square-on. It stood at radius
    162-168, rising to 226 — in the arm's path, at the arm's height, at all
    seven stops. The tag now lies flat in the mount's top face; camera_check
    says 48 degrees obliquity against a 60 degree limit.
    THE BEAM WAS LONGER THAN THE MACHINE. arm_len = R0+30, centred on the work
    line, driven through every station at exactly the height of thei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
    [body_clamp.FCStd, body_clamp.step, body_clamp.stl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]
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2026-07-27 S6 exists, the camera can see, and the ribbon is legible
    S6 DROP AND REJECT. The ticket asked for a chute with its mouth on the
    engagement plane. That framing was mine and it was wrong: the mouth has to be
    under the CABLE, and the arm holds the finished cable by its end at R=130 —
    68 mm inboard of the bolt circle, where a funnel would have been, with its
    inboard wall inside the arm's own envelope.
    So the chute is a hole in the deck with a printed collar around it and a bin
    underneath. One part at both stops, separate bins. The Z-travel saving that
    started this survives for a better reason than the one I gave: there is no rim
    to lift over because the bin is under the deck. Inboard edge is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
    [body_clamp.FCStd, body_clamp.step, camera_mount.FCStd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]
2026-07-27 Two things Kyle saw in the viewer: overlapping chutes, a floating camera
    "there are 2 trays now that intersect with each other ... also the black
    camera mount thingy still just floating in space."
    THE CHUTES OVERLAPPED BY 12 MM, and the cause is a derivation that quietly
    assumed a constant taken from a time when it was one.
    assign_station_angles() measured every stop's angular width at R0 — correct
    while every stop was AT R0. The S6 chutes are not: they sit at R=157, under
    where the cable hangs, and the same physical width subtends a bigger angle
    further in. It also measured the HOLE, when the collar around it is 38 mm
    wider and is what actually collides.
    Angular width is now taken at ea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
    [body_clamp.FCStd, body_clamp.step, camera_mount.FCStd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]
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2026-07-27 Real extrusion profile, and the three drives that were never drawn
    "the arm is a grey rectangle, but I think its ment to be the stock metal, we
    should fix that shape ... I think we have a plan for a specific part right,
    some sort of linear gear and motor to run up and down the arm? I dont see
    that at all."
    THE BEAM WAS A PLAIN BOX, and so was every frame member. 2020 and 3030 are
    T-slot profiles — that undercut is the entire reason you can bolt to them
    anywhere, and drawing bought stock as a featureless slab is the same lie as
    drawing the frame as a cylinder. build_parts now generates a real profile per
    distinct (size, length): four bars cover the whole machine. Modelled centred
    on the or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
    [body_clamp.FCStd, body_clamp.step, camera_mount.FCStd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]
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2026-07-27 Z deferred, the comb halves, and the wire is attached to something
    Z DEFERRED TO PHASE 2, as a FLAG not a deletion. Kyle: "we have done a ton of
    prelim there, and it may proove usefule when we get to adding station 4 and 5,
    or we may find out we can level all the stations and we dont need any z axis
    movment, so deferral."
    Z_STAGE_ENABLED = False. Everything stays — platform, post geometry, stroke
    selection, z_post_top(), clearance_check. Turning it True puts the axis back
    in one line. The rotor sits on a fixed 3030 pedestal at exactly the height the
    platform held it, so the swap moves nothing above it.
    z_stroke_active() is what the machine HAS; z_stage_choice() is what we would
    buy if we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
    [body_clamp.FCStd, body_clamp.step, body_clamp.stl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]
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
